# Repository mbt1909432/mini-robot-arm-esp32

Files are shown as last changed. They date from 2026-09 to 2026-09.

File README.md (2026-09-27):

# Mini Robot Arm for XIAO ESP32-S3

一套可打印、可校准、可通过浏览器控制的四轴桌面机械臂。这个仓库记录原始模型、本地结构改版、XIAO ESP32-S3 固件、网页控制台和验证脚本。

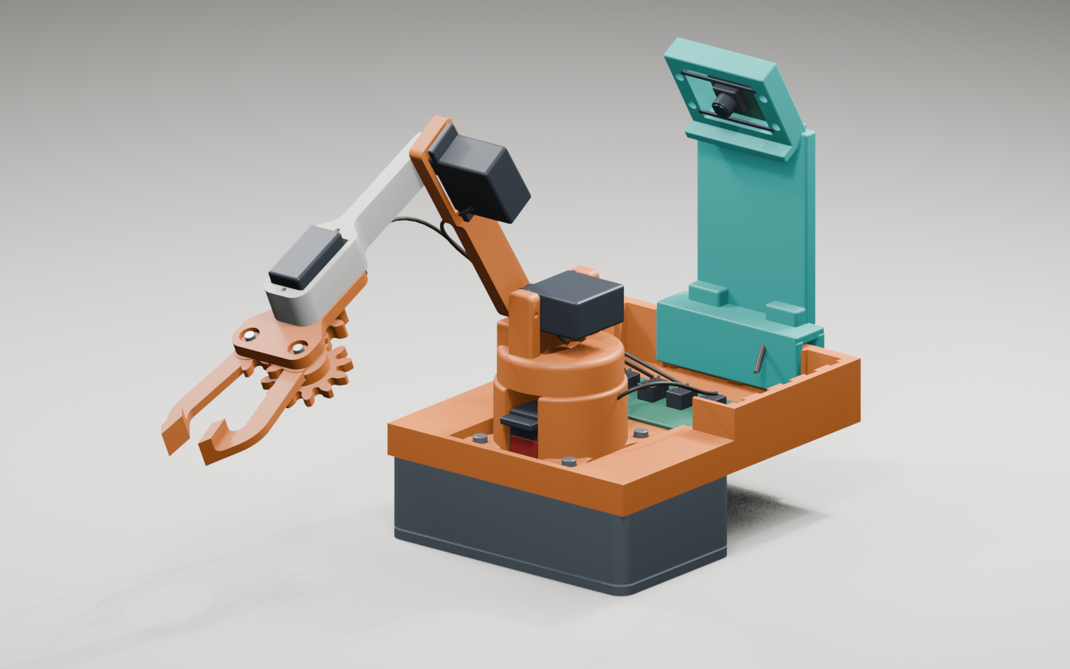
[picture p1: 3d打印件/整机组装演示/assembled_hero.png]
机械臂装配示意


## 已实现

- XIAO ESP32-S3 控制四个舵机：底座、大臂、小臂和夹爪。
- 手机或电脑连接机械臂热点后，通过 `http://10.10.10.1` 控制。
- 网页显示当前角度、目标角度和已保存的 Home 角度。
- 支持 1°、5°、10° 微调，Home 试运行、保存和恢复默认值。
- 支持柔和、标准、快速三档运动；默认柔和档按 1°/20 ms 逐步移动。
- Home 姿态写入 ESP32 闪存，重新上电后仍然保留。
- 关节软限位和渐进移动，降低直接撞到机械极限的风险。
- 提供不连接硬件的本地 UI 模拟预览。
- 保存舵盘槽、MG90S 底座避让和 XIAO ESP32-S3 Sense 摄像头支架的修改文件与脚本。
- 在 `原始代码/` 中保留改造前的固件、网页、接线图和来源说明，便于对比与恢复。

## 接线

| 关节 | XIAO 引脚 | GPIO | 舵机电源 |
| --- | --- | ---: | --- |
| 底座左右 LR | `D2` | 3 | 外部稳定 5V |
| 大臂前后 FB | `D3` | 4 | 外部稳定 5V |
| 小臂上下 UD | `D4` | 5 | 外部稳定 5V |
| 夹爪 Grip | `D5` | 6 | 外部稳定 5V |

四个舵机的红线接外部 5V 正极，黑色或棕色线接外部电源负极。**外部电源负极必须再接到 XIAO 的 GND。** XIAO 可以由 USB-C 单独供电；不要用 XIAO 的 3.3V 引脚给舵机供电，也不要把 2S 锂电池的原始 7.4V 直接接入舵机。

接线图见 [`代码/Circuit_bb.png`](代码/Circuit_bb.png)。

## 编译和烧录

Arduino IDE 中安装 ESP32 开发板支持与 `ESP32Servo`，开发板选择 `XIAO_ESP32S3`，打开：

`代码/91_Robot_Arm_ESP32/91_Robot_Arm_ESP32.ino`

Arduino CLI 示例：

```powershell
arduino-cli compile --fqbn esp32:esp32:XIAO_ESP32S3 代码/91_Robot_Arm_ESP32
arduino-cli upload -p COM8 --fqbn esp32:esp32:XIAO_ESP32S3 代码/91_Robot_Arm_ESP32
```

端口号按本机 `arduino-cli board list` 的结果修改。第一次通电和烧录后测试时，让机械臂悬空并从 1° 微调开始。

## 使用网页控制台

1. 连接 Wi-Fi `ESP32 Robot`，密码 `12345678`。
2. 浏览器打开 `http://10.10.10.1`。
3. 先选择 1° 步长，逐个关节确认运动方向与安全范围。
4. 在“开机姿态”中填写角度，先点“试运行这组角度”。
5. 确认结构没有顶住后，再点“保存为开机姿态”。

网页显示的是程序输出给舵机的角度，不是传感器测得的绝对角度。舵盘偏一个齿时，软件显示 90°，实物也可能不水平。
姿态图以一次实物照片中的 `FB 165°`、`UD 170°` 为方向和零点参考，只用于帮助辨认关节趋势，不替代实物校准。

## 本地预览界面

Windows 可双击 `启动前端预览.cmd`，或运行：

```powershell
python 代码/91_Robot_Arm_ESP32/preview_server.py --open
```

访问 `http://127.0.0.1:8765`。模拟服务器直接读取固件中的 `web.h`，所有动作只修改内存中的模拟角度，不会驱动真实舵机。

## 3D 文件和改版

- `3d打印件/`：原模型 STL 和随附 PDF。
- `3d打印件/舵盘槽调整/`：arm-1、arm-2 槽口放宽版、试装件、Blender 工程和脚本。
- `3d打印件/圆盘适配检查/`：MG90S 外壳避让试配件与几何检查。
- `3d打印件/拓竹导入/`：毫米单位的未切片 3MF。
- `3d打印件/摄像头支架改造/`：XIAO ESP32-S3 Sense 摄像头支架 STL、工程和生成脚本。
- `3d打印件/整机组装演示/`：装配场景、渲染图与可复现脚本。

这些几何改版中有一部分基于估算尺寸，仓库中的网格检查不等同于实物装配验证。打印完整件前，优先打印小试装件。

## 来源与许可

机械臂原模型来自 Arun Kumar 的 [Robotic Arm with a base for components](https://www.printables.com/model/1596575-robotic-arm-with-a-base-for-components)，基座等改版资料标注 RACBOTS。随附资料将模型标记为 [CC BY-SA 4.0](LICENSES/CC-BY-SA-4.0.txt)，本仓库保留署名，并以同一许可发布模型衍生文件。

Arduino 原始项目署名为 [Tech Talkies](https://www.youtube.com/@techtalkies1)，相关教程为 [ESP32 Robot Arm](https://www.youtube.com/watch?v=Qdebit3DgCE)。上游代码没有随附明确的开源许可证，因此本仓库不擅自为其指定许可证。详细边界见 [`NOTICE.md`](NOTICE.md)。

本地改动记录见 [`CHANGELOG.md`](CHANGELOG.md)。
改造前快照及已知问题见 [`原始代码/README.md`](原始代码/README.md)。

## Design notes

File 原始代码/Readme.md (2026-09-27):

# 原始代码快照

这里保存改造前收到的机械臂代码，便于比较、追溯和恢复。快照来源为：

`C:\Users\admin\Downloads\代码`

快照日期：2026-09-27。相同内容也曾保存在课程资料仓库提交 `82842e7` 中。

## 文件

- `91_Robot_Arm_ESP32/91_Robot_Arm_ESP32.ino`：原始 XIAO ESP32-S3 固件。
- `91_Robot_Arm_ESP32/web.h`：原始网页控制界面。
- `Circuit_bb.png`：原始接线图。
- `UPSTREAM-README.md`：随原始代码取得的 `Readme.md`；为避免与本索引在 Windows 上重名，仅调整了文件名，内容保持原样。

这些文件保持原样，不作为当前推荐版本。当前改进版位于：

`代码/91_Robot_Arm_ESP32`

## 已知问题

- 夹爪开机角度从 `0°` 开始，可能先撞到机械限位，再移动到打开位置。
- 所有关节允许 `0–180°`，没有针对打印结构的安全软限位。
- 网页以 50 ms 节流发送滑块数据，停止拖动时的最后一个角度可能没有发出。
- 页面不读取设备状态，刷新后显示值可能与机械臂当前目标不一致。
- 第一次调节任意滑块会同时发送页面中另外几个默认角度，可能引起意外移动。
- Reset 请求可能受到同一个 50 ms 节流限制而被忽略。
- 页面不显示请求失败、设备断线、当前角度或目标角度。

原始 Arduino 项目署名为 Tech Talkies YouTube Channel，但取得的文件没有随附明确的开源许可证。版权边界见仓库根目录的 `NOTICE.md`。

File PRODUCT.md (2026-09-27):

# Mini Robot Arm 产品设计基线

## 产品与用户

- **产品类型**：运行在 XIAO ESP32-S3 上的四舵机机械臂控制台，同时提供本地模拟预览。
- **主要用户**：第一次组装机械臂的学生、教师和创客；常用手机连接机械臂热点后操作。
- **核心任务**：看清连接状态，安全地逐关节调整角度，理解当前姿态与 Home 姿态的区别，试运行并保存开机姿态。
- **使用环境**：课堂、工作台和装配现场；屏幕可能较小，用户需要一边观察实物一边操作。

## 设计性格

- 精确、安静、可信，像一件小型测量仪器。
- 操作优先，状态和结果紧挨控件展示。
- 用少量信号橙标记主要动作，用蓝色表示选中与连接，用红色只表示危险或故障。

## 界面原则

- 首屏直接出现关节控制与姿态，不设置营销式大标题。
- 每个关节保留滑块、当前角度、Home 角度和微调按钮；触控区域不小于 44px。
- 当前值、目标值、已保存 Home 必须用文字和位置区分，不能只依赖颜色。
- Home 设置采用“编辑 -> 试运行 -> 保存”的明确顺序，危险操作需要确认。
- 手机端按操作顺序纵向排列，常用动作保持易触达。
- 支持键盘焦点、清晰对比度和 `prefers-reduced-motion`。

## 避免的方向

- 装饰性网格、霓虹赛博风和大面积深色背景。
- 巨幅标题、宣传文案、同构卡片墙和无意义状态卡。
- 只写 LR/FB/UD 等缩写而不说明关节作用。
- 用夸张动画掩盖控制延迟，或让动态内容引起布局跳动。

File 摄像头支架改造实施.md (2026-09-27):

# 迷你机械臂 + ESP32 摄像头支架改造实施

> 版本：V1 试装方案（2026-09-27）  
> 目标：在原始 1596575 机械臂模型上增加固定式摄像头安装结构。按用户已确认的 XIAO ESP32S3 Sense 设计，让摄像头从固定视角观察工作区；成品叠板、镜头和排线的精确尺寸仍需实测。  
> 当前阶段：V1 支架模型已生成并完成软件网格检查；尚未打印和装配验证。

## 1. 已确认的基础

- 原始机械臂来源为 Printables 模型 [Robotic Arm with a base for components](https://www.printables.com/model/1596575-robotic-arm-with-a-base-for-components)。本地资料中的 PDF 文件名也带有 `1596575` 和同名标题。
- 本地模型位于 `3d打印件/`，包括原始 STL、Blender 工程、修正版 STL 和拓竹 3MF。
- 原机械臂使用四个 MG90S 舵机，原接线保持不变：
  - D2 / GPIO3：底座左右；
  - D3 / GPIO4：大臂前后；
  - D4 / GPIO5：小臂上下；
  - D5 / GPIO6：夹爪。
- 舵机继续使用外部稳定 5V，舵机 GND 与 XIAO GND 共地；不使用 XIAO 3V3 给四个舵机供电。
- 用户已确认使用 XIAO ESP32S3 Sense。软件侧已有 Sense 摄像头配置，摄像头使用的 GPIO 与机械臂 GPIO3/4/5/6 分开。
- 当前照片可供判断安装位置和走线，不能作为精确尺寸图。最终卡槽要以 XIAO Sense 成品叠板的长、宽、总厚度，以及镜头位置和排线方向为准。

## 2. V1 结构决定

V1 采用“固定在底座后方的摄像头塔”方案：

1. XIAO Sense 摄像头组件固定在机械臂底座后侧或侧后方，并保持与主控板的原有连接；
2. 摄像头托框向前下俯 30°，让镜头朝向桌面工作区；实际视野仍以拍照结果为准；
3. 摄像头位置相对工作台保持不动，方便后续做坐标标定；
4. 支架做成独立可拆卸件，不直接切削或覆盖 `base1.stl`、`base-2.stl`、`arm-1.stl`、`arm-2.stl`；
5. V1 通过夹持结构搭在 `base_breadboard.stl` 的后墙上，后续根据实物墙厚调整夹口；
6. 使用开放式托架和绑带孔固定摄像头组件，安装时核对 USB-C、排线、舵机线和散热空间。

固定摄像头比把摄像头装到大臂、前臂或夹爪上更适合第一版。运动关节上的摄像头会增加末端重量、排线弯折和动态标定工作量。

## 3. V1 模型输出

生成文件放在 `3d打印件/摄像头支架改造/`：

- `xiao_sense_camera_mast_v1.blend`：可继续修改的 Blender 工程；
- `xiao_sense_camera_mast_v1.stl`：单件打印模型；
- `xiao_sense_camera_mast_v1_preview.png`：结构预览；
- `build_camera_mast_v1.py`：可复现的 Blender 建模脚本；
- `validation.json`：尺寸、孔位和网格检查结果。

V1 使用开放卡槽和绑带孔，尚未按实物叠板做紧配外壳。XIAO Sense 可以参考 Seeed 官方 DXF 尺寸，但排针、连接器、镜头和排线构成的总空间仍需实测。

当前模型参数：

| 项目 | V1 参数 | 使用说明 |
|---|---:|---|
| 支架外形 | 54 × 23.563 × 103.381 mm | 宽 × 深 × 高，按毫米导入切片软件 |
| 摄像头框开口 | 26 × 21 mm | 是托架开口，不代表板卡可用安装空间已确认 |
| 相机托框下俯角 | 30° | 固定角度，后续可修改脚本 `CAMERA_TILT_DEG` |
| 绑带孔 | 4 个，直径 3.1 mm | 左右框边各两个；使用能穿过孔的小绑带，不压镜头或排线 |
| 底座夹口 | 7.1 mm | 源模型后墙约 4 mm，留有约 3.1 mm 总余量 |
| 底座夹口适配 | 待试装 | 当前不能保证夹紧；需使用合适垫片，或按实测墙厚修改脚本参数 |
| 内侧加强筋避让 | 按原底座轮廓切出凹槽 | 刀具前移 0.3 mm，前爪局部留间隙；未改原底座 |

先在切片软件中截取夹口/托架，做局部试装并检查松紧，再考虑完整支架。不能依靠 3.1 mm 的空隙直接固定摄像头，否则支架晃动会改变视角，使后续标定失效。

图中橙色是原电子舱底座，青绿色是新增支架。STL 只包含青绿色部分；Blender 工程中保留橙色底座供装配参考，没有把它改写回原文件。图中没有装入主控板、摄像头或完整机械臂。

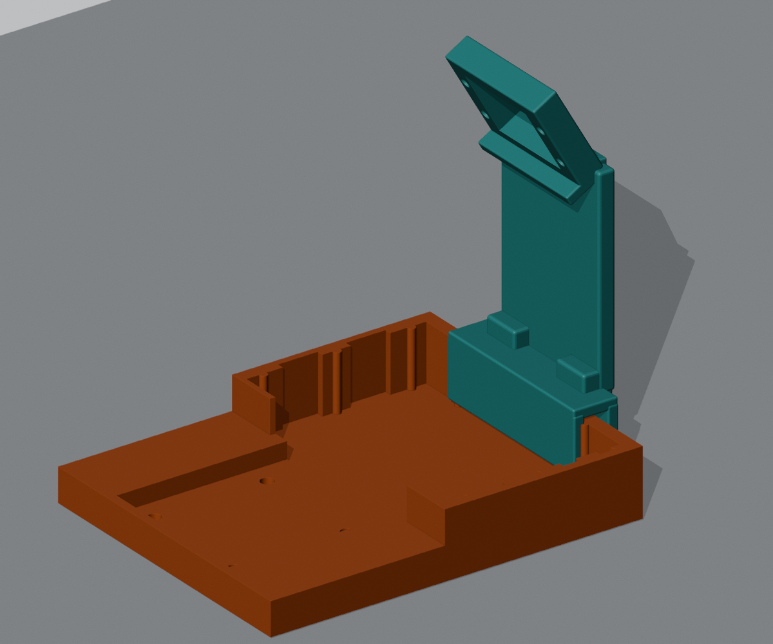
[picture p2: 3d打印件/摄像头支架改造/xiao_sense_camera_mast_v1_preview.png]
V1 后置摄像头支架结构预览


打印文件按毫米使用；STL 本身不带单位，导入后应核对上表尺寸。当前模型保留原底座坐标，切片时使用“放到打印床”调整位置。托盘和夹口存在悬空区域，切片时核对支撑及桥接，不提供未经切片/真机验证的 G-code。先用常用的 0.2 mm 层高做小件试装；完整件的壁数、填充和支撑要结合打印机与材料确认。

导出后的 STL 已重新导入校验：1 个连通实体、2812 个三角面、非流形边 0、零长度边 0、零面积面 0，实体体积约 26026 mm³。中心窗口和四个绑带孔共 90 条双向采样射线无遮挡；支架与原电子舱底座的静态布尔交集为 0。检查结果保存在 `validation.json`，脚本重新生成时会再次执行检查。这说明网格、采样通孔和名义底座位置通过检查，不代表镜头真实视场、夹紧力、承重、切片结果或真机装配已验证。

官方尺寸参考：

- XIAO ESP32S3 尺寸 DXF：<https://files.seeedstudio.com/wiki/SeeedStudio-XIAO-ESP32S3/res/XIAO_ESP32S3_v1.1_Dimensioning.dxf>
- XIAO Sense 扩展板顶/底部 DXF 可从 Seeed XIAO ESP32S3 资源页获取。

## 4. 软件实施顺序

本轮只改造模型并记录方案，没有修改 ESP-Claw 软件。仓库中已有摄像头拍照和颜色/运动检测的底层能力；网页摄像头预览、目标位置到机械臂动作的转换，以及自动抓取闭环尚未完成。下面是后续实施顺序，不是本轮已交付功能。

### 阶段 A：摄像头可用性

- 在 ESP-Claw 中打开摄像头；
- 调用 `take_picture` 保存一张 JPEG；
- 后续在网页增加拍照和预览入口；
- 确认镜头方向、曝光和工作区范围。

### 阶段 B：简单视觉

- 在工作区放置颜色明显的方块；
- 先用颜色检测得到目标像素位置；
- 网页同时显示原图、目标框和候选位置；
- 保留人工确认按钮。

### 阶段 C：坐标和动作

- 在工作台放置四个标记点；
- 建立像素坐标到工作台平面坐标的转换；
- 测量机械臂关节零点、臂长和安全工作范围；
- 实现目标位置到四路舵机角度的转换；
- 先执行“移动到目标上方”，再执行夹爪动作。

### 阶段 D：抓取反馈

- 记录抓取前后的照片；
- 检查目标是否仍在原位置；
- 增加停止、超时和人工接管；
- 再考虑自动执行，不把一次识别结果直接当成绝对正确的动作。

## 5. 验证顺序

1. 支架先单独试装，确认夹口、托架开口和固定方式；夹口松动时先加合适垫片或修改参数；
2. 装上实际主控板和摄像头，确认 USB-C、排线和 SD 卡仍可使用；
3. 机械臂断电时先检查静态间隙和走线；不要强行扳动舵机。之后按已校准的小范围、低速动作逐步检查各关节与支架的干涉；
4. 仅给 XIAO 通电，确认摄像头能拍照；
5. 单独给舵机外部 5V，确认共地；
6. 先用网页滑块测试机械臂，再测试颜色识别；
7. 完成后续标定和动作软件后，再进行低速、小范围、人工确认的抓取测试。

## 6. 需要实物复核的尺寸

- XIAO ESP32S3 Sense 成品叠板的实际长、宽、总厚度，包括已焊排针和连接器；
- 实际摄像头镜头相对板边的位置，以及镜头外径和凸出高度；
- 实际摄像头连接线的长度、弯曲方向和接头高度；照片里的白色线材不作为已确认的摄像头排线；
- 原底座后墙的实际厚度、高度和附近凸台/线材占用；若后续采用螺丝固定，还需核对可用孔中心距；
- 摄像头需要覆盖的工作区大小；
- 机械臂最大摆动范围和支架的避让距离。

因此，V1 STL 是试装模型，不等同于已经验证可以直接打印装配的最终件。实物测量和一次小件打印通过后，再生成 V2 紧配版和外观封闭版。

## 7. 照片与尺寸依据

- 板型按用户确认的 XIAO ESP32S3 Sense 处理，不根据这张照片另猜型号。
- 支架尺寸来自原始模型和可调整的 V1 设计参数；照片没有标尺，不能从照片直接量出可靠的孔距和配合公差。
- V2 紧配件需要成品叠板、摄像头和排线接口的实测长宽厚及安装方向，再锁定卡扣与孔位。

## 8. 当前边界

- 本次只增加摄像头安装模型并记录实施方案，没有改动软件和四个舵机的物理接线。
- 摄像头拍照、颜色/运动检测等底层能力已有；网页预览和“识别目标→坐标标定→逆运动学→抓取→结果反馈”仍需后续实现和真机验证。
- 模型尚未实物打印、试装，也未完成完整机械臂运动包络和实际视场验证。当前夹口有余量，不能把 V1 当成已经适配的最终件。

## 9. 整机拼装预览与动画（2026-09-27）

已将本地底座、两段臂、夹爪及新增支架组合为 Blender 示意装配场景，并提供 24 秒中文分步动画。入口：[整机组装演示](3d打印件/整机组装演示/组装演示.html)。文件、时间线、来源与验证范围见同目录 [使用说明](3d打印件/整机组装演示/使用说明.md)。

渲染包含整机、爆炸图、侧视图与相机特写；舵机、XIAO Sense 叠板、镜头、紧固件和线材是外观代理，未做厂家 CAD 级复刻。原接线和摄像头支架 STL 没有因演示而改变，动画不控制真机，也不代表整个运动范围已通过碰撞检查。

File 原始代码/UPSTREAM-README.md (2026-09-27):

# ESP32 Web-Controled Robotic Arm

A mobile-controlled robotic arm built using an ESP32 and standard hobby servos.  
The arm is controlled directly from a web browser, no mobile app required.

The ESP32 runs as a Wi-Fi access point and hosts a lightweight HTTP web interface with sliders and buttons to control each joint in real time.

---

## 💸 Get Your ESP32S3 at a Discount

[🛒 Buy the Seeed XIAO ESP32S3 from Seeed Studio](https://www.seeedstudio.com/XIAO-ESP32S3-p-5627.html?sensecap_affiliate=P9GHEkF&referring_service=link)

Use promo code **`N891LZX6`** at checkout for a discount!

---

## Features

- Web-based control (works on any phone or laptop)
- No external PWM driver board (no PCA9685)
- Hardware PWM using ESP32
- Smooth motion using target vs current angle control
- Reset / home function
- Optional vertical slider lock mode
- Designed for 2S Li-ion battery operation

---

## Hardware Used

- Xiao ESP32S3
- 4× Servo motors (MG90S or SG90)
  - Left–Right (Base)
  - Forward–Backward
  - Up–Down
  - Gripper
- External 5V supply (Regulated)

---

## Pin Configuration

| Function | Board Label | GPIO |
|---|---|---|
| Left–Right | D2 | 3 |
| Forward–Backward | D3 | 4 |
| Up–Down | D4 | 5 |
| Gripper | D5 | 6 |

## 🔧 Circuit diagram

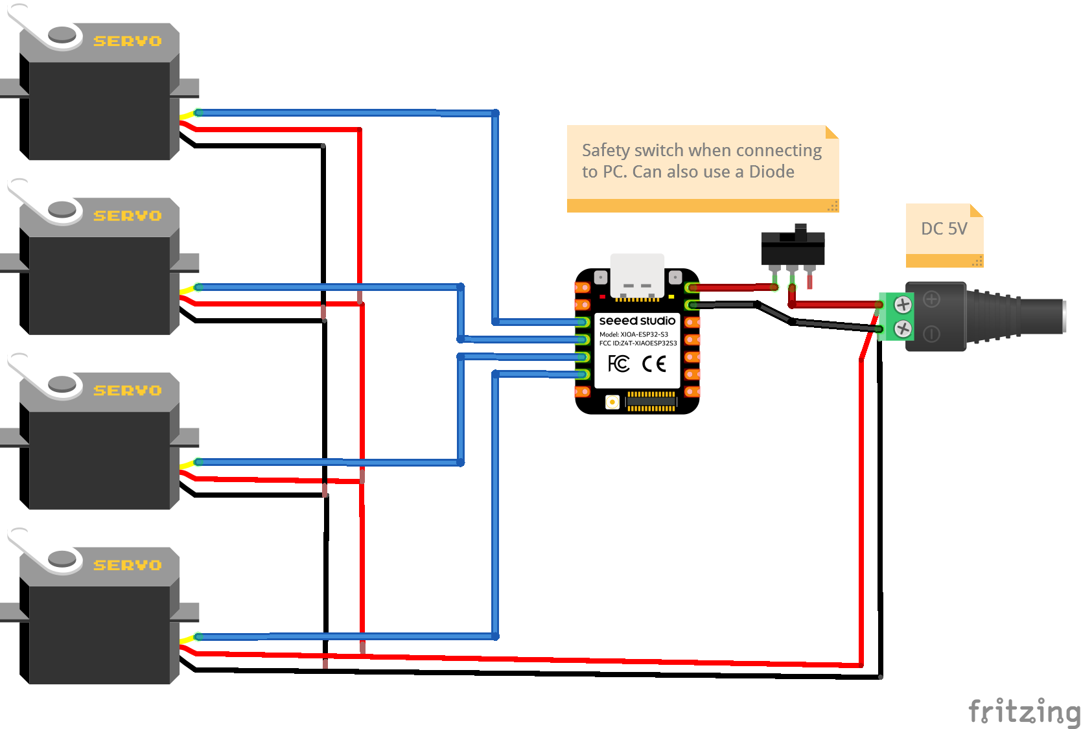
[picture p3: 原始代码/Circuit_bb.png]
Circuit diagram


---
Click on image for the video:

YouTube Video (https://www.youtube.com/watch?v=Qdebit3DgCE)

---

## Troubleshooting

### XIAO ESP32S3 + ESP32Servo multi-servo coupling

If you are using a **Seeed XIAO ESP32S3** and notice paired servo movement such as:

- moving the first vertical slider makes **D3 and D5** move together
- moving the horizontal slider makes **D2 and D4** move together

the wiring may be correct, but the problem can still be caused by the **ESP32Servo** library version.

In local testing, this issue appeared with newer `ESP32Servo` releases and was fixed by rolling back to an older `3.0.x` version of the library.

If you hit this behavior:

1. keep the board set to `XIAO_ESP32S3`
2. try an older `ESP32Servo` release such as `3.0.7` or `3.0.9`
3. retest before changing the wiring or code

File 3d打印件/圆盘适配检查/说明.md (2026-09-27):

# MG90S 凸起外壳避让试装版

用户通过照片确认：干涉对象是 MG90S 银色输出齿轴下面的黑色凸起齿轮外壳。对应旋转圆盘为 `../base-2.stl`，底部固定舵机的零件为 `base1.stl`。本次仅修改 base-2 的背面圆形凹槽。

## 修改

- 凹槽直径：约 20 mm → 22 mm。
- 凹槽深度：6 mm → 6.5 mm。
- 凹槽入口：新增 0.3 mm 倒角。
- 中心通孔约 7.5 mm、轴心位置、正面舵盘槽及上方支架保持原样。
- 原件不覆盖，没有修改舵机本身或固定底座。

没有收到凸台实测尺寸或装配间隙尺寸。上述数值是保守试配参数，并非根据照片量出的尺寸，不能保证一次解决干涉。原凹槽与正面舵盘槽间最薄约 2 mm，加深后约 1.5 mm，因此没有大幅挖深。局部减薄会降低余量，尚未进行承载或寿命验证。

## 文件

- `base-2_MG90S-clearance-D22-depth6.5_trial.stl`：完整试配模型。
- `base-2_MG90S-clearance_fit-test.stl`：保留整个背面接触形状、移除上方高支架的试装圆盘，仅用于检查干涉，不作为完整受力零件使用。
- `base-2_MG90S-clearance_trial.blend`：Blender 工程，原件和切割体隐藏保存。
- `base-2_clearance-validation.json`：网格、外形、上部连接形状和剩余厚度采样检查。
- `base-2_clearance_before.png`、`base-2_clearance_after.png`：修改前后凹槽预览。
- `adjust_base2.py`：可复现修改脚本，用 Blender 后台运行。

对应未切片 3MF 位于 `../拓竹导入/`，与上述 STL 同名；试装件 3MF 已翻转为凹槽朝上，平整切面贴打印板，减少凹槽顶面悬空。完整件保留原方向，需在 Bambu Studio 检查摆放和支撑。

## 试装

建议先按 100% 比例、毫米单位打印试装件。把凹槽面对舵机凸台轻放定位，检查接触和可转动间隙；不要靠螺丝强行把顶住的两件压合。连接舵机仍需要配套舵盘，光滑通孔不是花键连接。

照片中旧圆盘的凹槽底部存在明显松散料丝，可能是悬空面打印不佳或残留，实际试装前需排除这些料丝对落位的影响。

若试装仍顶住，记录是碰侧壁还是碰槽顶，并测凸台外廓和凸出高度。不能无限加深凹槽；高度仍不足时，应结合轴长、舵盘啮合和固定底座的舵机安装高度重新设计。

已验证导出 STL 为单一封闭实体、面方向一致、无退化三角面，外包围尺寸不变，凹槽上方原有顶点保留；以 576 条射线采样槽顶剩余厚度。3MF 已重新读取核对几何数据。未完成 Bambu Studio 实际导入、切片、打印、承载或实物装配验证。

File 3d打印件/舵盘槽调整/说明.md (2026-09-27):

# arm-1 舵盘槽放松版

根据实物照片和“稍微调大、通过螺丝固定”的要求，用 Blender 5.2.2 修改 `../arm-1.stl`。原文件未覆盖。尺寸按原 STL 的毫米坐标处理。

## 打印文件

- `arm-1_slot-plus-0.4mm.stl`：完整机械臂，替换原来的 arm-1。
- `arm-1_fit-test.stl`：26 × 12 × 5 mm 的局部试装件，包含与完整修改版一致的舵盘槽。建议先打印这个，确认黑色舵盘能装入，再打印完整件。
- `arm-1_slot-adjusted.blend`：可继续编辑的 Blender 文件，原件、切割体和试装件默认隐藏。

## 修改尺寸

| 位置 | 原尺寸 | 修改后 |
| --- | --- | --- |
| 嵌槽侧壁 | 原轮廓 | 向外偏移 0.4 mm，即总宽增加约 0.8 mm |
| 圆头嵌槽直径 | 约 7.0 mm | 约 7.8 mm |
| 长条末端槽宽 | 约 4.5 mm | 约 5.3 mm |
| 槽深 | 2.0 mm | 2.2 mm |
| 槽口 | 直角 | 0.2 mm 引导倒角 |

底部圆形通孔维持约 7.0 mm，轴心不移动；机械臂总长、外轮廓、舵机安装框及安装孔维持原尺寸。槽底剩余厚度为 2.8 mm，圆头外侧最薄处约 1.9 mm（倒角口处）。

切片时使用 100% 缩放、毫米单位，原来的平整底面向下，槽口朝上。试装件也使用与最终零件相同的材料和切片参数。

## 验证范围

已在 Blender 检查局部形状，并将导出 STL 重新导入，检查封闭性、面朝向、退化三角面、单一连通实体及体积。详细结果见 `validation.json`，修改前后图片为 `pocket_before.png` 和 `pocket_after.png`。

这是在没有实物测量值的情况下给出的装配余量版本，尚未完成实体打印和试装，不能保证一次适配。若圆头下面的凸台仍卡在底部通孔，或舵盘明显超过上述尺寸，应按实际卡住的位置继续调整；不要强压导致零件开裂。

`adjust_arm1.py` 为可复现修改脚本，只输出此文件夹中的派生文件，不修改原 STL。

## arm-2 同样调整

另一个相似零件是 `../arm-2.stl`，舵盘槽位于侧面。已核对其槽底轮廓与 arm-1 相同，按相同余量修改：侧壁向外偏移 0.4 mm、加深 0.2 mm、入口倒角 0.2 mm。轴孔、外轮廓、安装框及安装孔保持原尺寸和位置，原文件未覆盖。

- `arm-2_slot-plus-0.4mm.stl`：第二个零件的完整修改版。
- `arm-2_fit-test.stl`：第二个零件的局部试装件。
- `arm-2_slot-adjusted.blend`：第二个零件的 Blender 工程。
- `arm-2_validation.json`：网格与尺寸检查结果。
- `arm-2_pocket_before.png`、`arm-2_pocket_after.png`：侧面槽口修改前后预览。

arm-2 STL 保留原文件坐标方向，嵌槽朝侧面，不能直接套用 arm-1 的“原底面向下、槽口朝上”。在切片软件中检查摆放和支撑；局部试装件可旋转至槽口朝上打印。使用毫米单位、100% 缩放。尚未完成实物试装。

`adjust_arm2.py` 复用 arm-1 Blender 工程中的切割体，核对两者槽形一致后再转换方向并修改，只输出 arm-2 的派生文件。

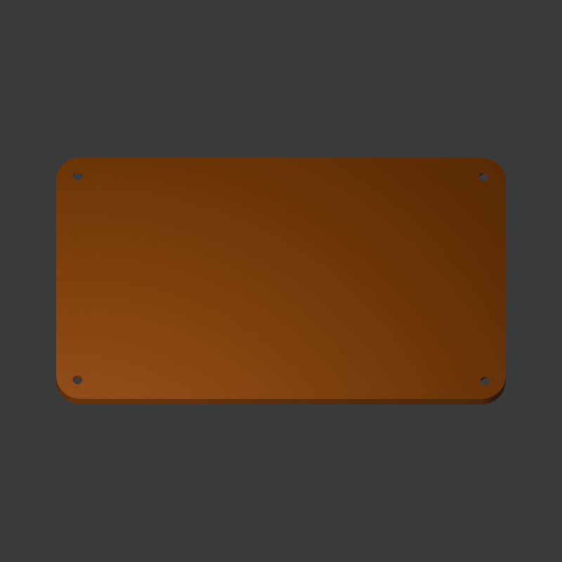
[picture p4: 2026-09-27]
3d打印件/圆盘适配检查/case_lid_top.png

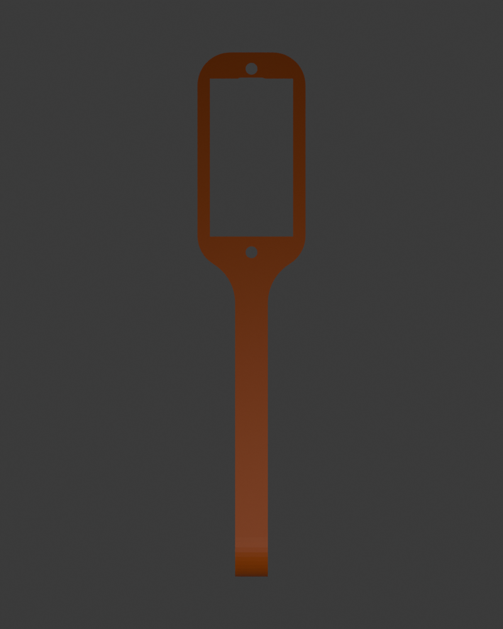
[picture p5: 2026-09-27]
3d打印件/舵盘槽调整/arm-2_top.png

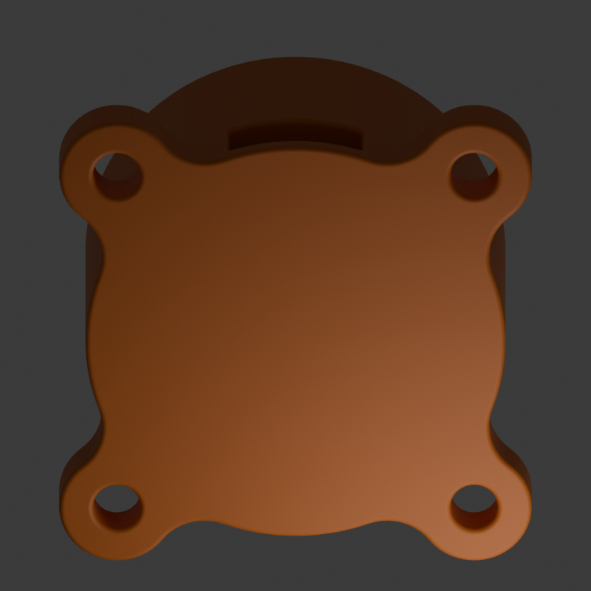
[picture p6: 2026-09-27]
3d打印件/圆盘适配检查/base1_bottom.png

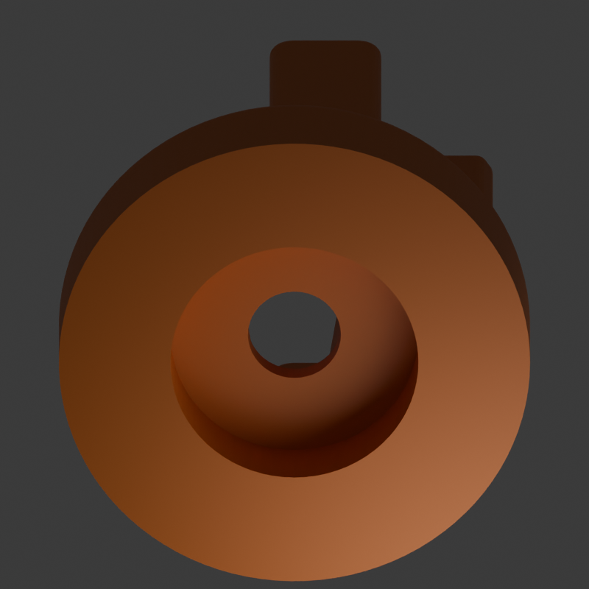
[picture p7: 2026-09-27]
3d打印件/圆盘适配检查/base-2_bottom.png

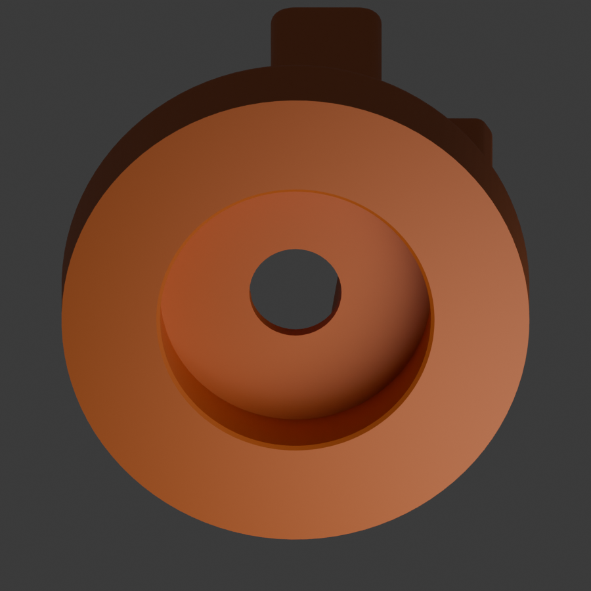
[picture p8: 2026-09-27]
3d打印件/圆盘适配检查/base-2_clearance_after.png

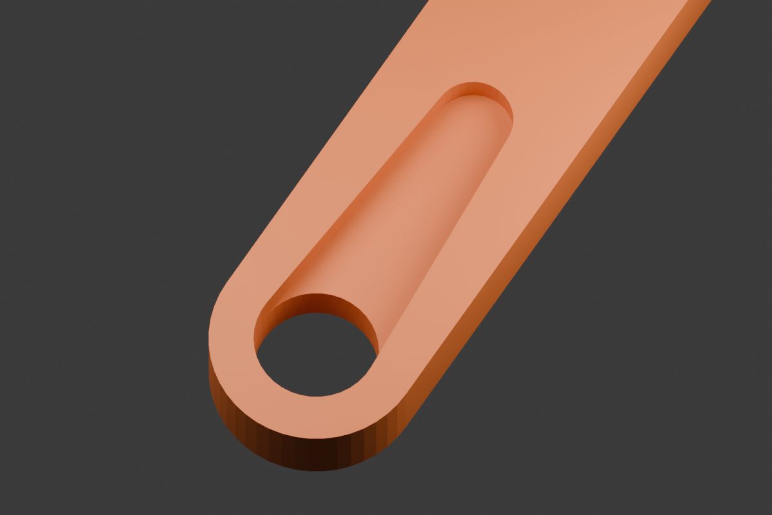
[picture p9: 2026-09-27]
3d打印件/舵盘槽调整/arm-2_pocket_before.png

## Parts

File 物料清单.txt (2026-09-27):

请自行淘宝购买，不推荐店铺。

XIAO ESP32S3开发板*1
MG90S舵机 *4
2*8cm 万用电路板 *1
ph2.0母端子头 *1
Type-C 2P带锁外螺牙母座 *1

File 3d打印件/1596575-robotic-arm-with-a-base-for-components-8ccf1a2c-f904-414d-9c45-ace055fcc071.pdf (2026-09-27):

## Robotic Arm with a base for

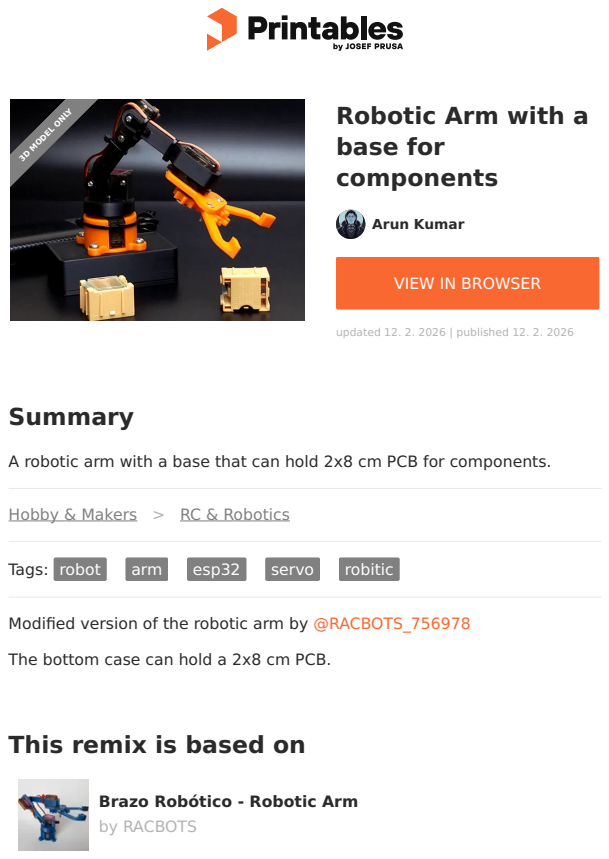
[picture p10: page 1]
Summary; Tags:; robot; arm; esp32; servo; robitic; Arun Kumar; components; updated 12. 2. 2026 | published 12. 2. 2026; 3D MODEL ONLY

VIEW IN BROWSER (https://printables.com/model/1596575-robotic-arm-with-a-base-for-components)

A robotic arm with a base that can hold 2x8 cm PCB for components.

Hobby & Makers (https://printables.com/model?categoryId=48) > RC & Robotics (https://printables.com/model?categoryId=64)

Modified version of the robotic arm by @RACBOTS_756978 (https://www.printables.com/@RACBOTS_756978)

The bottom case can hold a 2x8 cm PCB.

This remix is based on

Brazo Robótico - Robotic Arm (https://printables.com/model/449747-brazo-robotico-robotic-arm)
by RACBOTS (https://printables.com/@RACBOTS_756978)

## Model files

arm-1.stl

arm-2.stl

arm_support.stl

base-2.stl

base_breadboard.stl

base1.stl

case_lid.stl

case.stl

gear_arm1.stl

## License

This work is licensed under a
Creative Commons (4.0 International License)

Attribution-ShareAlike (http://creativecommons.org/licenses/by-sa/4.0/)

✖ | Sharing without ATTRIBUTION
✔ | Remix Culture allowed
✔ | Commercial Use
✔ | Free Cultural Works
✔ | Meets Open Definition

gear_arm2.stl

gear_servo.stl

gear.stl

tapa-v2.stl

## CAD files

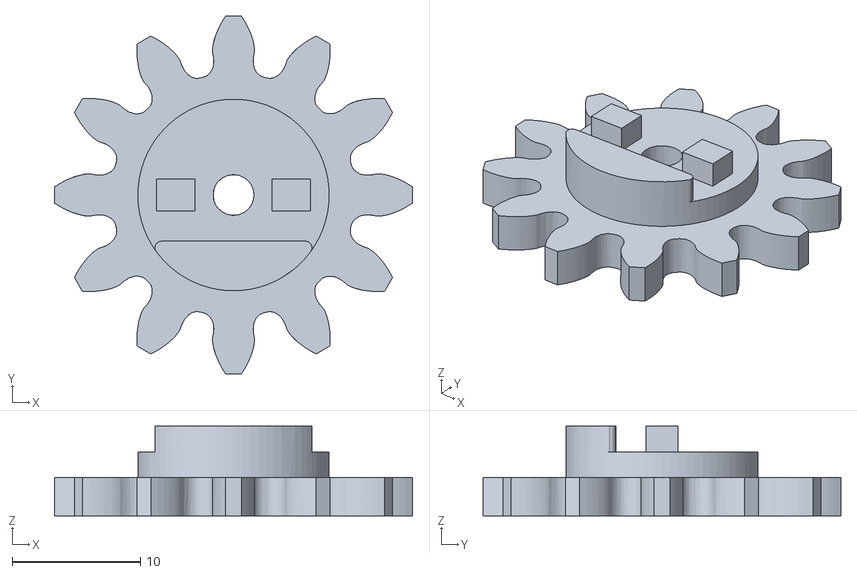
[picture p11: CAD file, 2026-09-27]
3d打印件/gear.stl
28.0 x 28.0 x 7.00

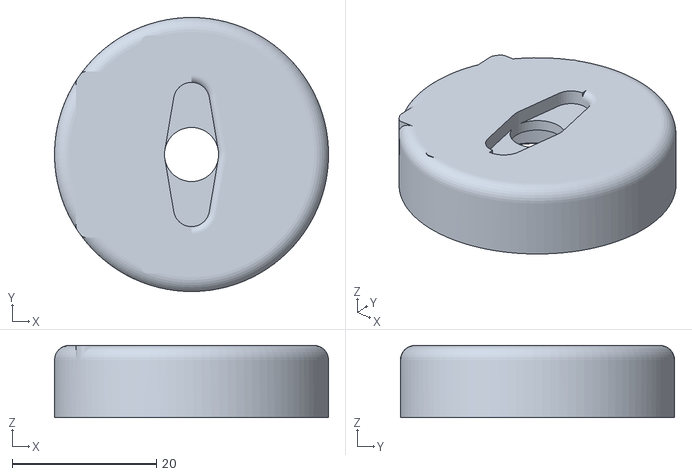
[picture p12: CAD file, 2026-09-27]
3d打印件/圆盘适配检查/base-2_MG90S-clearance_fit-test.stl
38.0 x 38.0 x 10.0

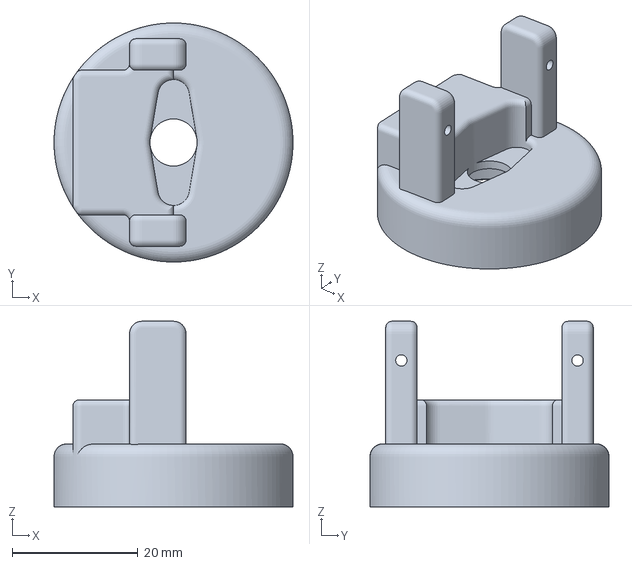
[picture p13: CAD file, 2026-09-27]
3d打印件/拓竹导入/base-2_MG90S-clearance-D22-depth6.5_trial.3mf
38.0 x 38.0 x 29.5 mm

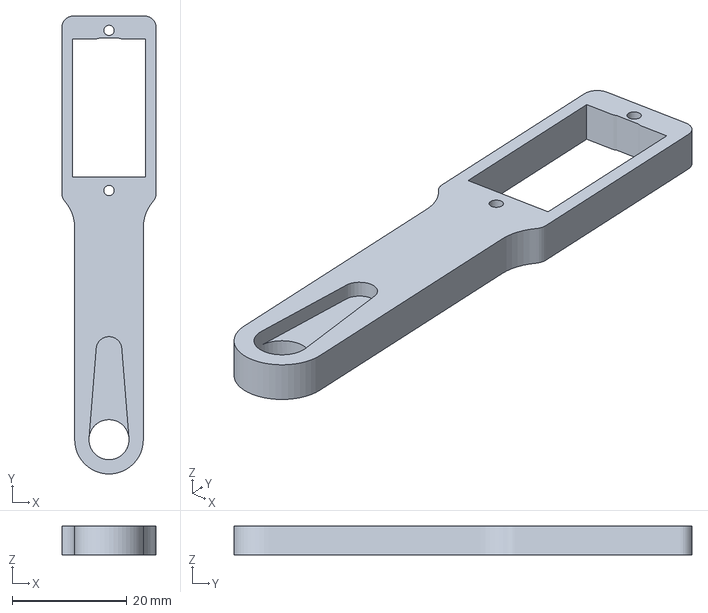
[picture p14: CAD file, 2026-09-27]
3d打印件/拓竹导入/original-reference/arm-1_original.3mf
16.5 x 80.0 x 5.00 mm

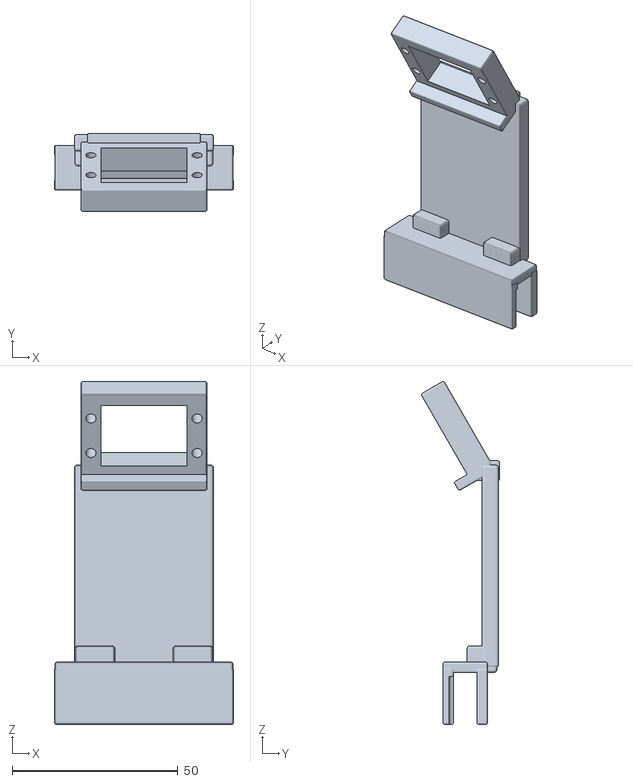
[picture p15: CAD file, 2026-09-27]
3d打印件/摄像头支架改造/xiao_sense_camera_mast_v1.stl
54.0 x 23.6 x 103.4

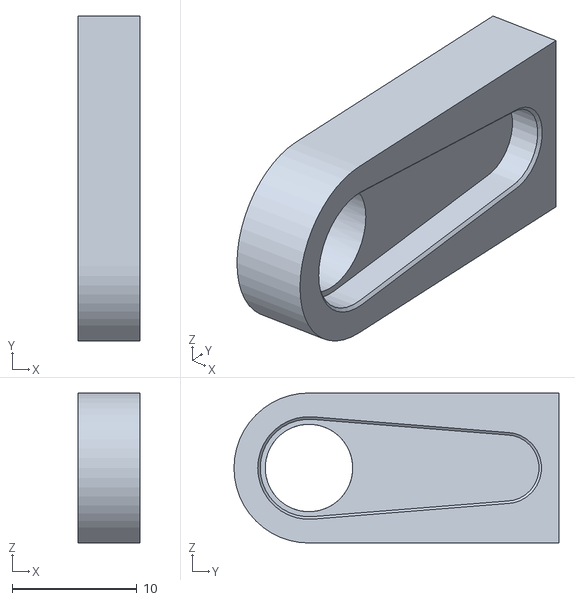
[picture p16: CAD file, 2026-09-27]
3d打印件/舵盘槽调整/arm-2_fit-test.stl
5.00 x 26.0 x 12.0

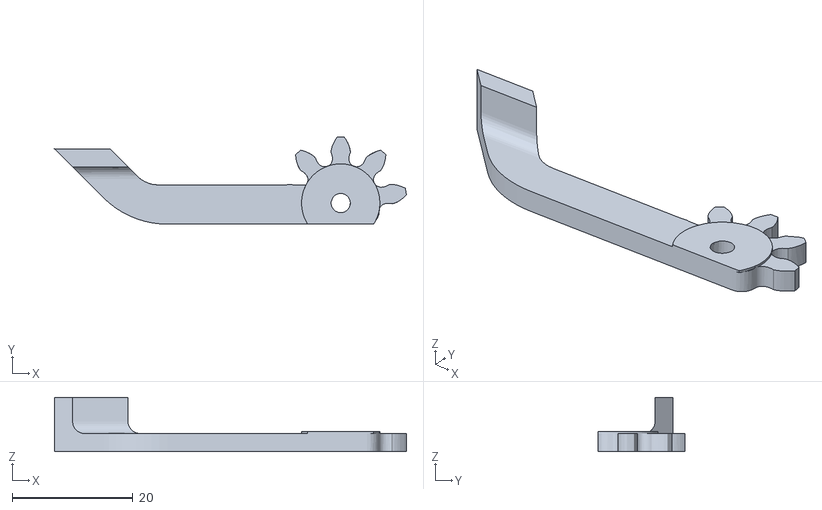
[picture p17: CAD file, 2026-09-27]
3d打印件/gear_arm2.stl
58.4 x 14.5 x 9.00

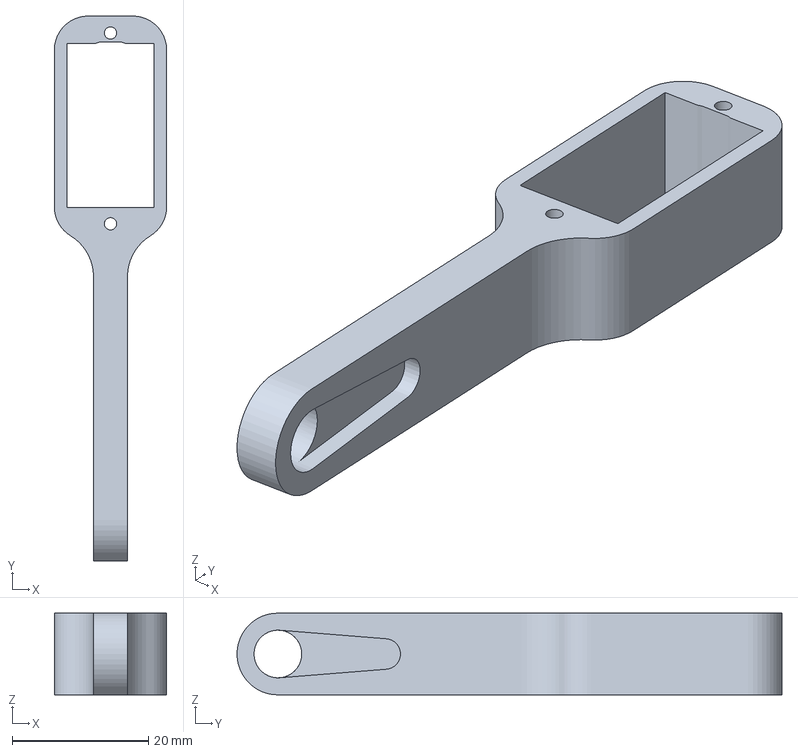
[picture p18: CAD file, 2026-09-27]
3d打印件/拓竹导入/original-reference/arm-2_original.3mf
16.5 x 80.0 x 12.0 mm

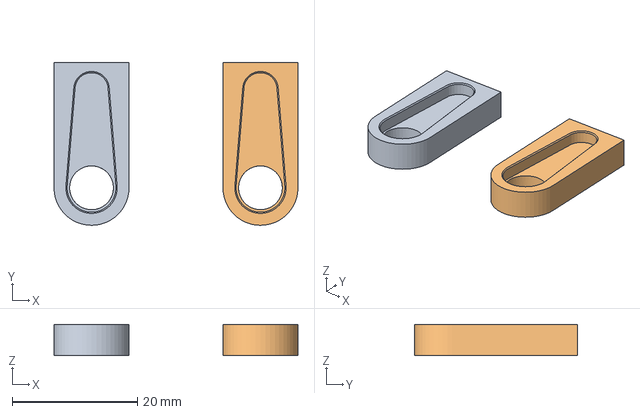
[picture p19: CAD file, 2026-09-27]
3d打印件/拓竹导入/fit-tests_pair.3mf
39.0 x 26.0 x 5.00 mm
arm-1_fit-test
arm-2_fit-test

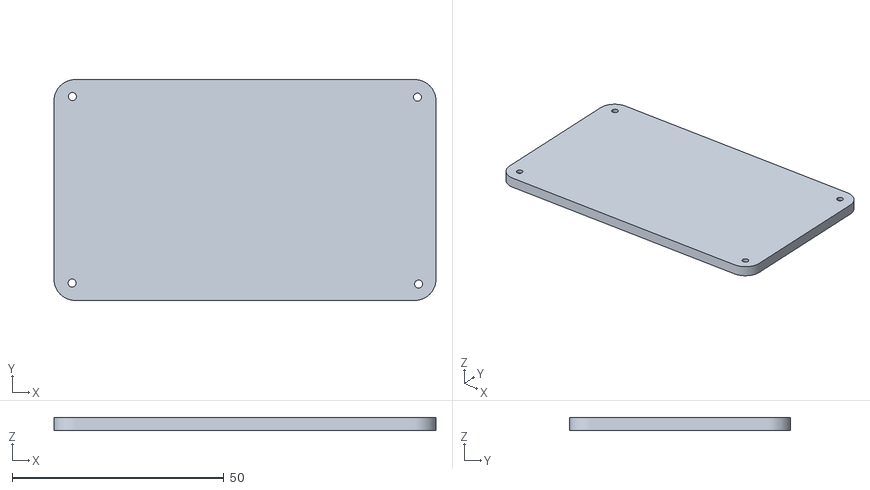
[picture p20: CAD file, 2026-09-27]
3d打印件/case_lid.stl
90.3 x 52.2 x 3.00

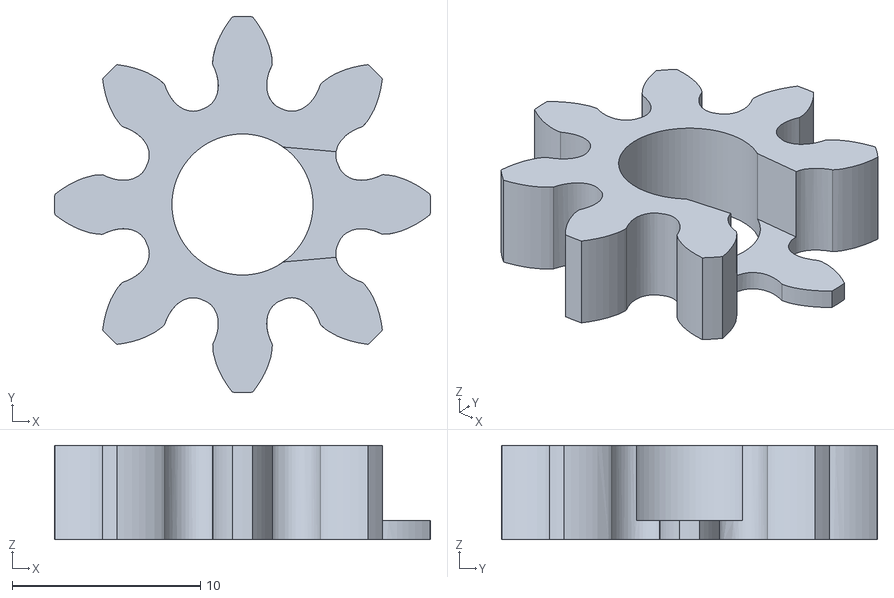
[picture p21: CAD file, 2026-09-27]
3d打印件/gear_servo.stl
20.0 x 20.0 x 5.00

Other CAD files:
3d打印件/圆盘适配检查/base-2_MG90S-clearance-D22-depth6.5_trial.stl
3d打印件/拓竹导入/arm-2_fit-test.3mf
3d打印件/舵盘槽调整/arm-1_slot-plus-0.4mm.stl
3d打印件/base-2.stl
3d打印件/舵盘槽调整/arm-2_slot-plus-0.4mm.stl
3d打印件/拓竹导入/arm-1_modified.3mf
3d打印件/舵盘槽调整/arm-1_fit-test.stl
3d打印件/arm-1.stl
3d打印件/arm-2.stl
3d打印件/arm_support.stl
3d打印件/base1.stl
3d打印件/base_breadboard.stl
3d打印件/case.stl
3d打印件/gear_arm1.stl
3d打印件/tapa-v2.stl
3d打印件/圆盘适配检查/base-2_MG90S-clearance_trial.blend
3d打印件/拓竹导入/arm-1_fit-test.3mf
3d打印件/拓竹导入/arm-2_modified.3mf
3d打印件/拓竹导入/base-2_MG90S-clearance_fit-test.3mf
3d打印件/拓竹导入/modified-arms_pair.3mf
3d打印件/摄像头支架改造/xiao_sense_camera_mast_v1.blend
3d打印件/整机组装演示/robot_arm_camera_assembly.blend
3d打印件/舵盘槽调整/arm-1_slot-adjusted.blend
3d打印件/舵盘槽调整/arm-2_slot-adjusted.blend

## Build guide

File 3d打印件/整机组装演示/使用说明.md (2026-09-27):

# 机械臂与摄像头：整机组装演示

本页用于看懂“原机械臂怎样组成整机、新增摄像头支架放在哪里”。它是离线教学演示，不连接开发板，也不会驱动舵机。

## 怎么看

1. 双击同目录的 `组装演示.html`，用 Edge、Chrome 或其他支持 MP4 的浏览器打开。
2. 点击“播放动画”。动画不会自动播放。可以拖动进度条、暂停，或改为 `0.5×` 慢速。
3. 右侧“想看哪一步？”可跳到对应章节；点击章节会先暂停，便于看清细节。
4. 下方四个视角可以分别查看整机、爆炸视图、侧面、摄像头细节。“放大原图”会打开完整图片。
5. 不想看运动时，切换“看静态步骤”。如果系统开启“减少动态效果”，网页会默认打开静态步骤。

键盘支持：

- `Tab` / `Shift+Tab`：移动焦点；`Enter`：使用按钮或链接。
- 焦点不在控件内时：空格播放或暂停，左右方向键前后移动 1 秒，`Home` 回到开头，`End` 到末尾，`F` 全屏。
- 四个视角按钮之间可以用方向键切换，`Home` / `End` 切到首尾。
- 焦点在视频自带控件、速度菜单、进度条内时，优先使用控件本身的键盘行为。

## 文件应放在一起

播放器引用以下同目录文件。若有媒体文件缺失，页面会显示提示；网页本身不会联网下载资源。

| 文件 | 用途 |
| --- | --- |
| `组装演示.html` | 离线播放器和静态说明 |
| `assembly_animation.mp4` | 组装动画 |
| `assembled_hero.png` | 整机效果 |
| `exploded.png` | 零件分离的爆炸视图 |
| `assembled_side.png` | 侧面效果 |
| `camera_detail.png` | 摄像头支架细节 |
| `robot_arm_camera_assembly.blend` | 可编辑 Blender 场景 |
| `assembly_manifest.json` | 实际模型、位置、时间线与校验记录 |

若视频无法播放，请先确认 MP4 与 HTML 的文件名和相对位置未改变。也可以直接用系统播放器打开 MP4，或继续看静态图。Blender 场景需用 Blender 打开。

## 什么是真实模型，什么是示意

- 塑料结构来自本地机械臂 STL 和新增支架模型。
- 舵机、开发板、镜头与线材为展示结构关系的代理模型，不是厂家精确 CAD。
- 用户使用的开发板为 XIAO ESP32S3 Sense；模型中的叠板厚度、镜头位置、连接位置和排线方向仍需依据实物测量复核。
- 动画是帮助理解连接关系的教学顺序，不是机械臂可以执行的轨迹，也不是经过工艺验证的装配作业指导书。
- 爆炸图为了看清零件而刻意把部件拉开，不能用这些间距指导打印或接线。

## 不要把渲染当成实物验证

该演示不代表已经完成：实体打印、卡扣/夹口试装、螺丝适配、舵机零位标定、布线、镜头视野验证或全行程碰撞测试。

原有四路舵机接线方案不因本次可视化改变。不得仅凭示意线材图直接接线。首次上电前，仍须依照已确认的电气接线文档逐项检查。

## 维护时间线

HTML 内的 `CHAPTERS` 数组集中保存章节起点、标题、说明和对应静态图编号。起点单位为秒，必须与实际渲染动画一致；以最终 `assembly_manifest.json` 的动画记录为准。静态图编号由 `VIEWS` 数组决定。

本版动画长 24 秒，24 fps，共 576 帧：

| 起点 | 观看内容 |
| --- | --- |
| 00:00 | 零件展开，先看总体组成 |
| 00:02 | 底座与电子舱 |
| 00:05 | 回转座与大臂 |
| 00:09 | 小臂与夹爪 |
| 00:13 | 摄像头支架与组件 |
| 00:17 | 拼好后绕机观察 |

颜色只用于识别：原底座与大臂为橙色，小臂浅灰白，新增摄像头支架青绿色，舵机炭黑色，PCB 绿色。它们不是电气接线颜色。

## 原模型来源与署名

原机械臂设计为 **RACBOTS** 的「Brazo Robótico - Robotic Arm」；本地使用的是 **Arun Kumar** 的带元件底座改版 [Robotic Arm with a base for components](https://www.printables.com/model/1596575-robotic-arm-with-a-base-for-components)。本地原始 PDF 注明 [CC BY-SA 4.0](https://creativecommons.org/licenses/by-sa/4.0/) 许可。本装配场景中的衍生网格继续按同一许可提供。改动包括舵盘槽试配版本、新增摄像头支架、模型重定位、颜色和装配动画；示意电子器件为本地生成。分享衍生模型时应保留署名、许可和改动说明。

## 在 Blender 里自己看

打开 `robot_arm_camera_assembly.blend`，时间轴停在第 432 帧（已经拼好）。切到相机视图可看当前取景；普通三维视图可绕模型旋转。

- 第 1 帧：零件展开。
- 第 108 帧：底座与电子舱合拢。
- 第 204 帧：回转座与大臂合拢。
- 第 305 帧：小臂与夹爪合拢。
- 第 408 帧：摄像头和支架合拢。
- 第 432—576 帧：相机绕整机观察，机械臂保持同一姿态。

在时间轴点击播放即可看关键帧动画。对象按 01—10 组命名；示意硬件对象带有 `is_visual_proxy` 属性，不应导出为打印件。`tapa-v2.stl` 与 `base-2.stl` 是替代造型，本场景只使用后者。夹爪采用上下两层齿轮关系：下层小轮驱动与一片夹爪同轴的大轮，上层两夹爪相互啮合；齿相位和螺丝深度仍需实物确认。

## 重现与检查

`build_assembly.py` 用原 STL 生成场景、四张静态效果图和装配记录；`encode_animation.py` 将 576 张帧图编码为带中文步骤标题的 MP4。静态图用 Blender Eevee，视频用 Workbench 以保证步骤清晰。模型以毫米定义，整体按 0.001 缩放到 Blender 的米制场景。

```powershell
& 'D:\blender\blender.exe' -b --python-exit-code 1 --python '.\build_assembly.py'
& 'D:\blender\blender.exe' -b '.\robot_arm_camera_assembly.blend' -s 1 -e 576 -a
python '.\encode_animation.py'
```

在本文件夹运行上述命令。重新生成会覆盖本文件夹内的场景/效果图/视频；需要保留手工调整时，先把 `.blend` 另存为新名称。不会覆盖原始 STL。

已做文件级验证：13 个输入网格哈希未改变；全部 576 帧的物体包围盒都在画面内；MP4 为 H.264、24 fps、24 秒，已完整解码检查；四张效果图及多个动画阶段已视觉检查。检查数据在 `assembly_manifest.json`、`framing_validation.json` 和 `media_validation.json`。

HTML 已做脚本语法和控件逻辑检查。内置浏览器禁止自动打开本地 `file://` 页面，本次未完成真实浏览器的播放交互验收；如当前应用不支持页面预览，直接在 Edge/Chrome 中打开 HTML，或用本地播放器打开 MP4。

本演示采用项目暖纸色、深蓝文字和有限强调色；页面不使用 CDN、远程字体、在线脚本或自动播放。

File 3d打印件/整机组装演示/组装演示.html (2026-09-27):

迷你机械臂 / 摄像头改造离线演示 · 不连接真机

ASSEMBLY STUDY / V1

# 拼起来，就是这样。

先看原来的机械臂，再看新支架放在哪里。动画可以随时暂停，细节也可以单独放大。

试装方案
VISUAL PREVIEW

看组装动画看静态步骤

底座 / 大臂小臂新增支架舵机示意件

已按系统的“减少动态效果”偏好打开静态步骤。仍可由你手动切换动画。

当前浏览器不能播放视频，请查看下方静态图或用本地播放器打开 assembly_animation.mp4。数字装配演示 · 非实拍

动画进度，单位为秒00:00 / --:--

播放动画回到开头全屏速度

键盘：空格播放 / 暂停，← → 前后 1 秒，Home 回开头，F 全屏。也可使用视频自带控件。

## 想看哪一步？

点一步跳到对应位置；不会自动开始播放。

## 不看动画，也能顺着装起来

下面是理解结构的阅读顺序。真正装配时，还需要检查螺丝、舵机零位和实际间隙。

## 换个角度，看清楚。

重点看：支架与底座的关系、镜头朝向和机械臂活动空间。

机械臂与后置摄像头支架的整机渲染预览

整机效果

从整体看机械臂和后置摄像头支架的相对位置。

放大原图 ↗

## 哪些是真的模型？

塑料结构使用本地机械臂 STL 和新增支架模型。舵机、XIAO ESP32S3 Sense、镜头及线材是帮助理解位置的示意件，不是厂家精确 CAD。叠板厚度、连接位置和排线方向仍需实测确认。

## 看懂位置，不等于装配已验证

- 这是教学展示顺序，不是机器人可执行的运动轨迹。
- 未完成实体打印、装配与全行程碰撞测试。
- 原接线方案保持不变；播放此页面不会驱动机械臂。

想自己转动查看？用 Blender 打开完整场景。

Blender 场景动画文件使用说明模型与动画记录

V1 可视化试装 · 全部资源位于同一文件夹，无需联网。硬件示意、打印适配与电气接线须分别确认。

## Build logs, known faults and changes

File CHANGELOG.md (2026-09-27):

# 修改记录

## 2026-09-27

- 将主控适配为 XIAO ESP32-S3，并固定四路舵机引脚为 D2、D3、D4、D5。
- 增加关节软限位、渐进移动、状态接口和浏览器微调。
- 使用 ESP32 `Preferences` 保存开机 Home 姿态。
- 增加 Home 数字输入、试运行、保存和恢复默认值。
- 重做网页控制台：关节控制、动态姿态示意和 Home 校准集中在一个操作台中。
- 优化控制延迟：滑块始终发送松手时的最终目标，拖动期间状态轮询不再覆盖控件；舵机缓动更新从 2°/20 ms 调整为 3°/15 ms。
- 根据实物照片重新校正网页姿态预估的关节方向和零点，并明确标注它不是传感器反馈。
- 增加柔和、标准、快速三档运动；默认柔和档以 1°/20 ms 移动，减少 MG90S 的逐级顿挫感。
- 增加直接读取 `web.h` 的本地模拟预览服务器。
- 增加 XIAO ESP32-S3 Sense 摄像头支架和整机装配演示资料。
- 将改造前收到的固件、网页、接线图和说明作为原始快照纳入 Git，并记录已知问题。

## 2026-09-18

- arm-1、arm-2 舵盘槽每侧外扩约 0.4 mm，并保存试装件、Blender 工程和检查记录。
- 增加 MG90S 底座圆盘避让试配版。
- 生成供 Bambu Studio 导入的毫米单位 3MF 文件。

## 原始资料

- 机械臂模型：Arun Kumar；基座等改版资料标注 RACBOTS。
- Arduino 项目：Tech Talkies。

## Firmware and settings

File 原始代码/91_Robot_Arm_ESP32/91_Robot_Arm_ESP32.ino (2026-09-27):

/* -------------------------------------------------
Copyright (c)
Arduino project by Tech Talkies YouTube Channel.
https://www.youtube.com/@techtalkies1
-------------------------------------------------*/

#include <WiFi.h>
#include <WiFiAP.h>
#include <WebServer.h>
#include <ESP32Servo.h>
#include "web.h"

const char* ssid = "ESP32 Robot";
const char* password = "12345678";

WebServer server(80);

static const int servoPinLR = D2;
static const int servoPinFB = D3;
static const int servoPinUD = D4;
static const int servoPinGrip = D5;

Servo servoLR, servoFB, servoUD, servoGrip;

int lr_target = 90;
int fb_target = 90;
int ud_target = 90;
int grip_target = 0;

int lr_current = 90;
int fb_current = 90;
int ud_current = 90;
int grip_current = 0;

const int GRIP_OPEN = 180;
const int GRIP_CLOSE = 60;

const int STEP_ARM = 2;   // smooth arm motion
const int STEP_GRIP = 5;  // faster gripper

void handleServo() {

  if (server.hasArg("lr"))
    lr_target = constrain(server.arg("lr").toInt(), 0, 180);

  if (server.hasArg("fb"))
    fb_target = constrain(server.arg("fb").toInt(), 0, 180);

  if (server.hasArg("ud"))
    ud_target = constrain(server.arg("ud").toInt(), 0, 180);

  if (server.hasArg("grip")) {
    int g = server.arg("grip").toInt();
    grip_target = (g == 1) ? GRIP_CLOSE : GRIP_OPEN;
  }

  Serial.printf("T -> lr:%d fb:%d ud:%d grip:%d\n",
                lr_target, fb_target, ud_target, grip_target);

  // Quick ACK
  server.send(200, "text/plain", "ok");
}

void setup() {
  Serial.begin(115200);
  WiFi.mode(WIFI_AP);
  WiFi.softAP(ssid, password);
  delay(1000);
  IPAddress IP = IPAddress(10, 10, 10, 1);
  IPAddress NMask = IPAddress(255, 255, 255, 0);
  WiFi.softAPConfig(IP, IP, NMask);
  IPAddress myIP = WiFi.softAPIP();
  Serial.print("AP IP address: ");
  Serial.println(myIP);

  /* SETUP YOR WEB OWN ENTRY POINTS */
  server.on("/servo", handleServo);

  // Route for root / web page
  server.on("/", HTTP_GET, []() {
    server.send_P(200, "text/html", index_html);
  });

  server.begin();
  Serial.println("HTTP server started");

  Serial.begin(115200);
  servoLR.attach(servoPinLR);
  servoFB.attach(servoPinFB);
  servoUD.attach(servoPinUD);
  servoGrip.attach(servoPinGrip);
}

void loop() {
  server.handleClient();
  delay(2);  //allow the cpu to switch to other tasks

  static unsigned long lastUpdate = 0;
  if (millis() - lastUpdate >= 20) {
    lastUpdate = millis();

    // Left / Right
    if (lr_current < lr_target) lr_current += STEP_ARM;
    else if (lr_current > lr_target) lr_current -= STEP_ARM;
    if (abs(lr_current - lr_target) < STEP_ARM) lr_current = lr_target;

    // Forward / Backward
    if (fb_current < fb_target) fb_current += STEP_ARM;
    else if (fb_current > fb_target) fb_current -= STEP_ARM;
    if (abs(fb_current - fb_target) < STEP_ARM) fb_current = fb_target;

    // Up / Down
    if (ud_current < ud_target) ud_current += STEP_ARM;
    else if (ud_current > ud_target) ud_current -= STEP_ARM;
    if (abs(ud_current - ud_target) < STEP_ARM) ud_current = ud_target;

    // Gripper (faster, or even snap if you want)
    if (grip_current < grip_target) grip_current += STEP_GRIP;
    else if (grip_current > grip_target) grip_current -= STEP_GRIP;
    if (abs(grip_current - grip_target) < STEP_GRIP) grip_current = grip_target;

    // ---- ACTUAL SERVO OUTPUTS HERE ----
    servoLR.write(lr_current);
    servoFB.write(fb_current);
    servoUD.write(ud_current);
    servoGrip.write(grip_current);
  }
}

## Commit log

2026-09-27 发布 XIAO ESP32-S3 迷你机械臂项目
    [arm-1.stl, arm-1_fit-test.3mf, arm-1_fit-test.stl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]
2026-09-27 降低网页控制延迟
2026-09-27 校准姿态预估并改善舵机平滑度
2026-09-27 保存机械臂原始代码快照
